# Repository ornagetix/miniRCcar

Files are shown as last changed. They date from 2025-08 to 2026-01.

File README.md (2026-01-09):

# miniRCcar

### A Hot Wheels car transformed into a miniature, WiFi-controlled RC car using an ESP32-C3

This repository documents the design and development of a compact, rear-wheel-drive mini RC car built from a modified Hot Wheels chassis.

The car is controlled wirelessly through a web-based interface hosted directly on the ESP32-C3, requiring no external apps.

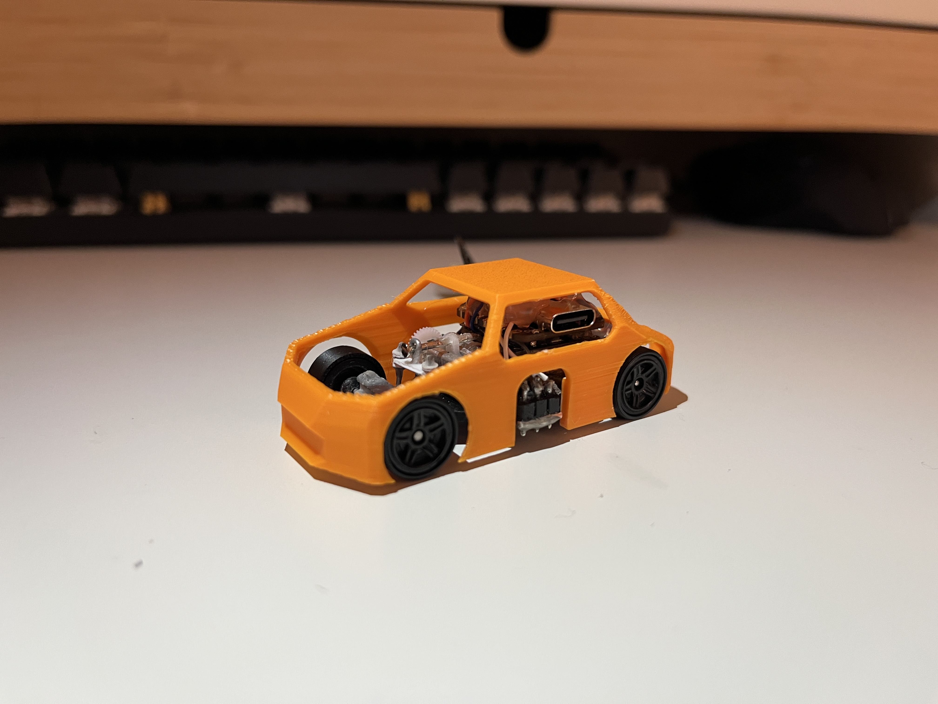
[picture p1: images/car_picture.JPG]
picture of finished car


## Overview
I remember coming along [this](https://www.youtube.com/watch?v=nx7Ih79KevE) tutorial online by [Max Imagination](https://www.youtube.com/@MaxImagination) a while back about creating a miniature RC car using components solely housed inside of the metal body of Hot Wheels car. 

His project intrigued me so much that I decided to attempt and create my own iteration of a miniature RC car using a similar manufacturing process: I took apart one of my own Hot Wheels cars at home, carved down the plastic chassis, and added my own components on it. I even tried creating a custom metal body by adding my own paint finish; however, the metal body didn't fit with the chassis anyway, leading me to improvise by designing my own body in Onshape and 3D printing it myself.

I took great inspiration from the tutorial while also using my skills in electronics that I learned when I built an electric vehicle for Science Olympiad, designing my own steering mechanism and wiring system. The tutorial initially included a camera integrated on the car as well, but I didn't see a point for it as it would only decrease the poor battery life of the car even more (the drive motor of the car uses significant amounts of current). 

**All of the code is written solely by myself with the help of AI.**

Despite many aspects of the car being based off the tutorial, this project was still a very extensive learning curve for me. The goal of this project was for me to learn and explore embedded systems, wireless control, and mechanical integration all incorporated together.  
The ESP32-C3 serves as both the real-time controller and the web server, enabling direct browser-based control of steering and throttle.

This repository contains the **entire development history**, including iterative firmware changes, hardware integration, and testing.

## Features

- Web-based control interface hosted on the ESP32-C3
- Real-time motor and steering control via. JWT
- WiFi access point hosted on device
- Compact Hot Wheels–scale chassis

## System Architecture

The system consists of three primary layers:

- **Embedded Controller**  
  ESP32-C3 handling control logic, WiFi networking, and web hosting

- **Control/Logic Layer**  
  Motor driver and servo logic translating web inputs into physical motion

- **User/Web Interface**  
  Lightweight HTML/CSS/JS controller page served directly from the ESP32

> Architecture and wiring are detailed in the wiring diagram below.

## Hardware

- Microcontroller: seeed studio XIAO ESP32-C3
- Chassis: Modified Hot Wheels car (Volkswagen Golf Mk7)
    - Chassis is modified from Hot Wheels car, body is 3D printed
- Drive Motor: Dual-shaft N20 DC brushed motor
- Steering: AGFRC C1.5CLS micro linear servo
- Motor Driver: *DRV8833* (breakout board)
- Power: 55mAh lithium-polymer battery (3.7V)

## Wiring Diagram

The following diagram shows all electrical connections between the ESP32-C3, motor driver, servo, and power system.

wiring diagram

## Software Stack

- PlatformIO
  - Embedded Arduino/C++ framework, compact libraries 
- HTML / CSS / JavaScript
  - Web-based control interface

## Repository Structure

```text
├── src/            # Firmware source code
├── include/        # Header files
├── data/           # Web server files (HTML/CSS/JS)
├── images/         # Wiring diagrams, images, and 
screenshots
├── cad/            # .STEP files of CAD models
├── platformio.ini  # Build configuration
└── README.md
```

## CAD
I dimentioned the currently constructed car at the time and designed my own, custom body relative to the car's current dimensions in Onshape.

The Onshape document can be viewed [here.](https://cad.onshape.com/documents/029913163f88ca92eb8538c8/w/90c467ae5afbd02c9b09910f/e/cb22bba638a81b7ee942d32d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)

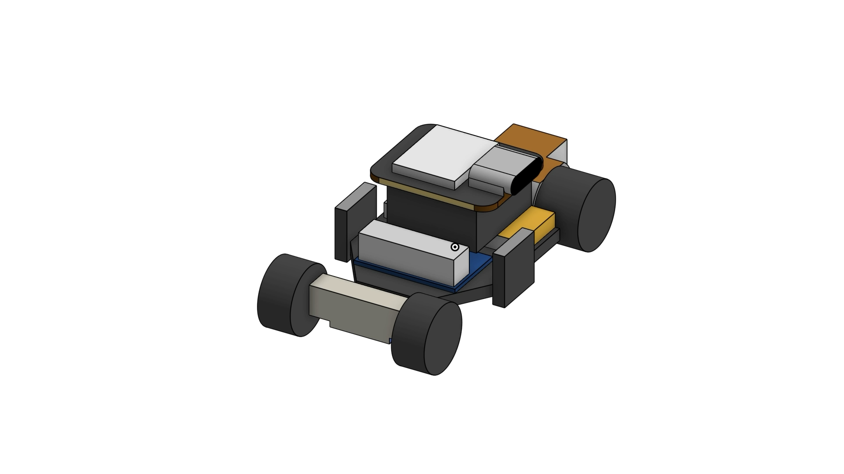
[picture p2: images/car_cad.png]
original car construction

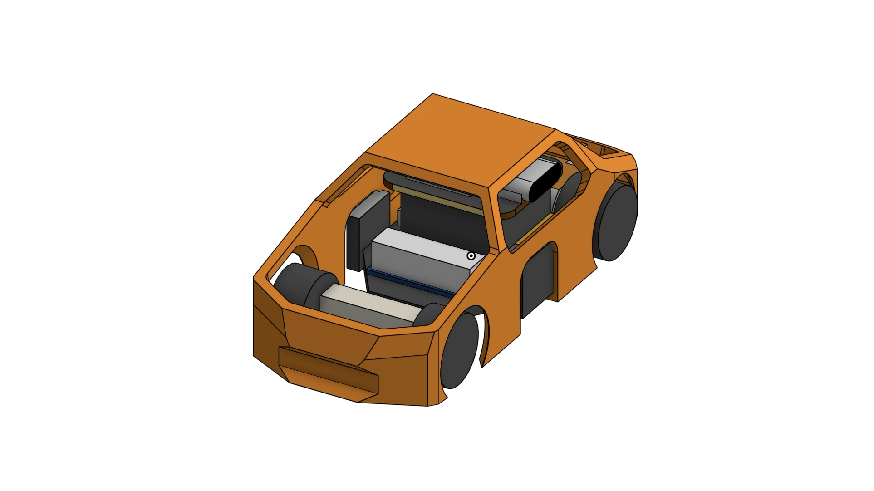
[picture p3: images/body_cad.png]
body designed around car


# Bill of Materials
| Item Name | Sales Price | Retailer | Sales Price + Sales Tax (6%) |  |
| --- | --- | --- | --- | --- |
| Hot Wheels Car (Volkswagen Golf MK7) | n/a |  | n/a |  |
| [seeed studio XIAO ESP32C3 (Microcontroller)](https://www.amazon.com/Seeed-Studio-XIAO-ESP32C3-Microcontroller/dp/B0B94JZ2YF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)  | 9.9 | Amazon | 10.494 |  |
| [Old DC Motor (extracted from servo)](https://www.aliexpress.us/item/3256806385982254.html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)  | 0.99 | AliExpress | 1.0494 |  |
| Current DC Motor (page doesn't exist now) | 2.29 | AliExpress | 2.5648 | *bought 2 because one broke (1.10 + 1.19) |
| [AGFRC C1.5CLS micro linear servo (right)](https://www.aliexpress.us/item/3256806392339708.html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)  | 11.69 | AliExpress | 13.0928 | *bought 2 because one broke (4.61 + 7.08) |
| [DRV8833 motor driver (breakout board)](https://www.aliexpress.us/item/3256805965029595.html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) | 1.43 | AliExpress | 1.5158 | ^ got expensive quickly wow |
| [55mAh lithium-polymer battery (3.7V)](https://www.aliexpress.us/item/3256806678850434.html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) | 7.28 | AliExpress | 7.7168 |  |
| [SS12D00 SPDT switch](https://www.aliexpress.us/item/2255801021214741.html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) | 0.99 | AliExpress | 1.0494 |  |
| [32-gauge wire](https://www.aliexpress.us/item/3256803980811288.html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) | 0.89 | AliExpress | 0.9434 |  |
| Total | 35.46 | w/ Sales Tax | 38.4264 |  |
| *all items are 1 count |  |  |  |  |

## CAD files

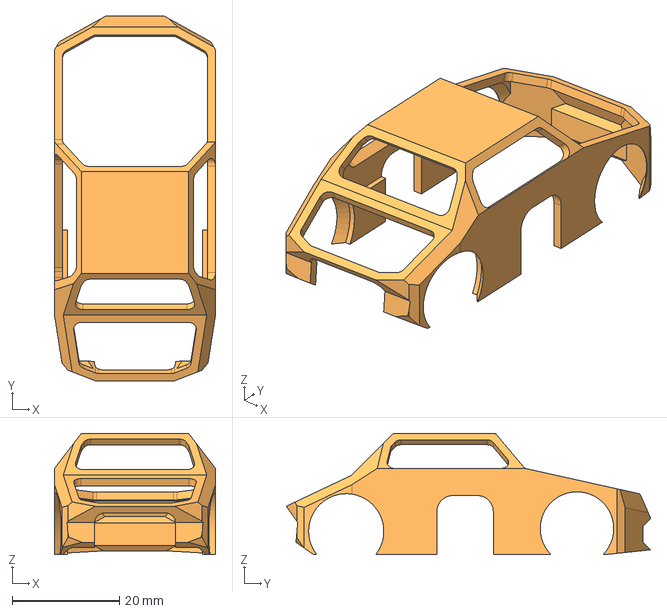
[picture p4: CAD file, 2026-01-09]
cad/miniRCcar_body.step
30.0 x 67.9 x 22.6 mm

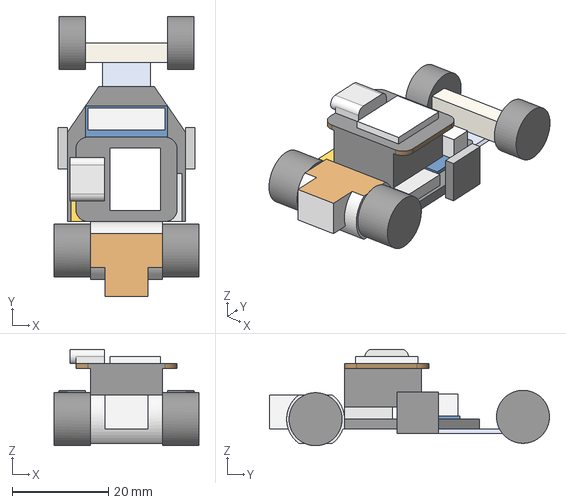
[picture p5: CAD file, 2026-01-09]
cad/miniRCcar_chassisandelecs.step
30.0 x 58.0 x 20.0 mm

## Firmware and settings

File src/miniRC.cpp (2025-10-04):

#include <Arduino.h> // arduino core library
#include <ESP32Servo.h> // servo class

#include <WiFi.h> // wifi library
#include <AsyncTCP.h> // async tcp library
#include <ESPAsyncWebServer.h> // web server library
#include <AsyncWebSocket.h> // websocket library
#include <ArduinoJson.h> // json library

#include <FS.h> // main filesystem library
#include <LittleFS.h> // littlefs filesystem library

// define motor pins and PWM channels
#define in1 2
#define in2 3
#define motorFreq 5000
#define motorRes 8

// setup motor and servo pins
#define servo_pin 4

// creates servo object for servo (to attach servo & use methods)
Servo servo;

// setup WiFi credentials
const char* ssid     = "miniRCcar";
const char* password = "screwdriver123";

// setup web socket
AsyncWebServer server(80); // web server on port 80
AsyncWebSocket ws("/ws"); // websocket endpoint (path is /ws)

// function prototypes
void setThrottle(int speed);
void setAngle(int angle);
void onWSEvent(AsyncWebSocket *server, AsyncWebSocketClient *client, AwsEventType type, void *arg, uint8_t *data, size_t len);

void setup() {
  // starts serial monitor
  Serial.begin(115200);
  delay(5000); // Give time for serial monitor to connect
  Serial.println("\n5s wait for media & serial connection..."); // wait for serial monitor to connect via USB

  // initialize motor PWM channels
  ledcSetup(in1, motorFreq, motorRes);
  ledcSetup(in2, motorFreq, motorRes);
  ledcAttachPin(in1, in1);
  ledcAttachPin(in2, in2);

  servo.attach(servo_pin); // initialize servo pin
  servo.write(90); // reset servo to default position

  // setup LittleFS file system
  if (!LittleFS.begin() && !LittleFS.begin(true)) {
    Serial.println("An error has occurred while mounting LittleFS");
  } else {
    Serial.println("LittleFS mounted successfully!");
  }

  File f = LittleFS.open("/index.html", "r");
  if (!f) {
    Serial.println("Webpage not found in LittleFS");
  } else {
    Serial.println("Webpage exists in LittleFS!");
    f.close();
  }
  
  // setup access point
  Serial.println("Setting up car access point...");
  WiFi.softAP(ssid, password, 1, 0, 1);
  Serial.println("Car access point started!\n");

  // add web files from /data folder to LittleFS
  server.serveStatic("/", LittleFS, "/").setDefaultFile("index.html");

  // setup & start web socket
  ws.onEvent(onWSEvent);
  server.addHandler(&ws);
  server.begin();
  Serial.println("Web server started!");
}

// websocket event handler
// handles events like connect, disconnect, and sending motor & servo commands
void onWSEvent(AsyncWebSocket *server, AsyncWebSocketClient *client, AwsEventType type, void *arg, uint8_t *data, size_t len){
  switch (type) {
    case WS_EVT_CONNECT: // client connected
      Serial.printf("WebSocket client #%u connected from %s\n", client->id(), client->remoteIP().toString().c_str());
      break;
    case WS_EVT_DISCONNECT: // client disconnected
      Serial.printf("WebSocket client #%u disconnected\n", client->id());
      break;
    case WS_EVT_DATA: // data received from client (web server sends commands)
      // parse json data
      JsonDocument doc;
      DeserializationError error = deserializeJson(doc, (char*)data);

      // handle json parsing error
      if (error) {
        Serial.print(F("deserializeJson() failed: "));
        Serial.println(error.f_str());
        return;
      }

      // extract and set motor speed and servo angle from json
      int motorSpeed = doc["throttle"]; // get motor speed value
      int servoAngle = doc["steerAngle"]; // get servo angle value
      setThrottle(motorSpeed); // set motor speed
      setAngle(servoAngle); // set servo angle

      // print values in serial monitor
      Serial.printf("throttle: %d, angle: %d\n", motorSpeed, servoAngle);
      break;
  }
}

bool infoPrinted = false; // value to ensure info is printed only once
void loop() {
  // print access point info only once
  if (!infoPrinted) {
    //delay(5000); // wait for access point to initialize
    Serial.print("Car SSID: ");
    Serial.println(WiFi.softAPSSID());
    Serial.print("Car IPv4 address: ");
    Serial.println(WiFi.softAPIP());
    infoPrinted = true;
  }
}

/*
  sets motor speed and direction
  speed range: -255 to 255
  negative speed = reverse direction
  positive speed = forward direction
  zero speed = stop motor
*/
void setThrottle(int speed) {
  if (speed > 0 && speed <= 255) {
    ledcWrite(in1, speed);
    ledcWrite(in2, 0);
  } else if (speed < 0 && speed >= -255) {
    ledcWrite(in1, 0);
    ledcWrite(in2, speed);
  } else if (speed == 0) {
    ledcWrite(in1, 0);
    ledcWrite(in2, 0);
  } else {
    Serial.println("invalid speed");
  }
}

// sets the servo/steering angle
// angle range: 50 to 120
void setAngle(int angle) {
  if (angle >= 50 && angle <= 120) {
    servo.write(angle);
  } else {
    Serial.println("invalid angle");
  }
}

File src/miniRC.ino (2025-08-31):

#include <ESP32Servo.h> // servo class
#define in1 D0
#define in2 D1
#define servo_pin D2

// creates servo object for servo (to attach servo & use methods)
Servo servo;

void setup() {
  // put your setup code here, to run once:

  // initialize motor pins
  pinMode(in1, OUTPUT);
  pinMode(in2, OUTPUT);

  // initialize servo pin
  servo.attach(servo_pin);
  // reset servo to zero
  servo.write(0);

  // starts serial monitor
  Serial.begin(9600);
}

void loop() {
  // put your main code here, to run repeatedly:
  // MOTOR TEST CODE
  analogWrite(in1, 255);
  digitalWrite(in2, LOW);

  // SERVO TEST CODE
  servo.write(50);
  delay(1000);
  servo.write(90);
  delay(1000);
  servo.write(120);
  delay(1000);
  servo.write(90);
  delay(1000);
}

void setMotor(int speed) {
  if (speed > 0 && speed <= 255) {
    analogWrite(in1, speed);
    digitalWrite(in2, LOW);
  } else if (speed < 0 && speed >= -255) {
    digitalWrite(in1, LOW);
    analogWrite(in2, speed);
  } else if (speed == 0) {
    digitalWrite(in1, LOW);
    digitalWrite(in2, LOW);
  } else {
    Serial.println("invalid speed");
  }
}

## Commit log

2025-08-31 refactor(motor): switch from Arduino analogWrite/digitalWrite to ESP32 ledCWrite
2025-09-15 fix: use and setup default WiFi library (w/ web server and access point)
    [miniRC.cpp]
2025-09-15 style: add comment to explain motor speed and direction control
2025-09-18 feat: create steering method, prepare webserver/websocket with AP
2025-09-26 fix test code for serial output
    [miniRC.cpp]
2025-09-27 test: working motor/servo and access point test code
2025-10-03 add and verify web server/website, fix LittleFS setup, refactor web server handler
    [miniRC.cpp]
2025-10-04 fix json sending/recieving (deserialization)
    [miniRC.cpp]
2025-10-04 update steering center value to be 90 degrees (for servo)
2025-10-04 Revert "update steering center value to be 90 degrees (for servo)"
    This reverts commit cef9c1095e0afadcf76662afee7b30e603d9eb48.
    [miniRC.cpp]
2025-10-04 fix setAngle() angle mapping
    [miniRC.cpp]
2025-10-04 inflate throttle range and ensure steerAngle centers at 90 degrees
2026-01-07 refine hardware section in README for clarity on chassis and components
2026-01-09 refine README contents, add BOM & .STEP files of CAD models
    [miniRCcar_body.step, miniRCcar_chassisandelecs.step]
2026-01-09 remove empty row in BOM table in README
